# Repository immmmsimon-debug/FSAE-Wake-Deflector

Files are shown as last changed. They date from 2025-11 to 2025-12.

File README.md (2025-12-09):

# FSAE-Wake-Deflector
* The goal of this project is to design an aerodynamic wake deflector to manage the turbulent flow (“dirty air”) generated by the front tires of an FSAE car. This flow interferes with the undertray and side channel, reducing downforce and stability. The deflector aims to shield the side channel inlet from tire wake and to generate vortices that enhance undertray performance during both straight-line and cornering conditions.

## Fundamentals: 
- Open-wheel cars, including Formula SAE designs, suffer from highly turbulent flow around the front tires. As the tire rotates, the airflow separates along its shoulders, forming strong lateral vortices and a low-energy wake behind it. This unsteady, chaotic region—often called “dirty air”—contains low total pressure and high turbulence intensity.
When this wake interacts with the undertray or side channel inlet, it reduces the available clean flow that generates ground-effect downforce. In simple terms, the wake pollutes the undertray’s airflow, decreasing suction and stability.
### Flow Shielding and Redirection
- One approach to mitigating this is flow shielding, where an aerodynamic surface (such as a deflector wall) blocks or redirects the tire wake. However, this solution has limitations. A solid wall creates a stagnation zone on its upstream side and often leads to flow separation downstream, introducing drag and further turbulence.
Therefore, the better approach is flow redirection rather than pure blocking. By shaping the deflector with curvature or an airfoil profile, the air can be guided smoothly around the wake region, preserving flow energy and directing cleaner, higher-momentum air toward the undertray inlet.
### Vortex Generation and Control
- A more advanced strategy—used extensively in Formula 1—is vortex generation. Controlled vortices act like rotating tubes of high-energy air that can “seal” the underfloor, much like virtual skirts. The swirling motion of a vortex pulls faster air from above into the lower boundary layer, re-energizing it and delaying flow separation.
In the context of an FSAE car, the wake deflector can be designed with an airfoil-like geometry or sharp turning edge to induce a pressure difference between its suction and pressure sides. The rolling-up of flow at the deflector’s tip produces a coherent vortex that travels along the side channel, maintaining undertray suction.<br />
However, vortex behavior is highly sensitive to its environment. Its strength, trajectory, and longevity depend on:
  - Pressure gradient along its path.
  - Proximity to solid surfaces, which induce viscous shear.
  - Contamination by surrounding turbulence, such as tire wake.
### Viscous Dissipation and Vortex Decay
- Even if a strong vortex is generated at the inlet, it can decay rapidly due to viscous dissipation. This term describes how internal friction within the air (viscosity) converts the vortex’s organized rotational kinetic energy into heat and small-scale turbulence.
As the vortex interacts with the ground plane and side channel walls, shear layers form that gradually sap its energy. The higher the viscosity effects and turbulence intensity, the faster this decay occurs.
### Application to FSAE Scale
- At the FSAE scale, vortices are smaller and more sensitive to Reynolds number effects. This means they dissipate faster than in F1-scale aerodynamics, where higher speeds sustain coherent vortex structures. Therefore, achieving a long-lived vortex in FSAE requires careful balance: it must be strong enough to survive viscous losses, but not so aggressive that it causes flow separation or drag.
Reference: Willem Toet, “Motorsport Diffusers,” Racetech Magazine, 2017.
(https://www.racetechmag.com/2017/08/willem-toet-explains-motorsport-diffusers/)

### Constraint
  Because the deflector mounts around the A-arm and runs very close to the ground, the design uses a modular, multi-panel approach with localized doubler plates and through-bolt attachments to prevent fastener shear-out in the carbon-fiber honeycomb sandwich. Sacrificial UHMW skid strips and aramid-reinforced outer plies protect the laminate from abrasion and low-energy ground strikes; skids are bolted to backing plates so they are quickly replaceable. Fastener regions are either through-bolted to a backing plate or use bonded aluminum doublers with stainless steel threaded inserts to spread bearing loads and prevent core crush. All quick-release hardware is installed over doublers and captive nut plates to enable rapid service while preserving structural integrity. In order to test the mounting and the height of the deflector, we made flat plate deflector that is the same size as the curve ones, to see how much will scrap off and does the deflector survibe the impact.
<p align="center">
  
Screenshot 2025-12-08 at 12 50 07 AM

</p>

## CFD Images of Baseline Design

- The baseline configuration was analyzed using CFD, focusing on total pressure (CPt) distribution. Lower CPt regions correspond to higher-speed flow, or turbulance zone. The way that we can differenciate is by looking at the shape of the and the way it change, since a vortex would be circular and push air arround it in the dircection of its rotation while turbulance would seem chaotic and unpredictable. 
The results show a vortex forming near the deflector and propagating toward the side channel inlet. The high-speed circular region in the CPt plot confirms vortex formation. However, the vortex weakens and dissipates before reaching the end of the side channel, indicating a loss of potential downforce. <br />

https://github.com/user-attachments/assets/b7ffb7f3-22c6-420c-961b-e3214d9e8f9d

- In this video and  image we can see the vortex generated by the deflector and its position in relation to the side channel inlet by the looking at the CPt, see that there is a high air speed zone in a circular shape. As the vortex progress through the side channel we can see that it does not survibe at the lowest point of the side channel losing potential downforce being created, there are some assumption as to why this happend. 
     - The vortex core is too weak to survive the full channel length.
     - The channel geometry is too low, causing early vortex breakdown.
     - Insufficient clean flow enters the inlet, with some of the tire wake contaminating the vortex despite the deflector wall.
- In the baseline CFD, the observed weakening of the vortex near the outlet of the side channel can be explained by viscous dissipation combined with insufficient clean flow. The tire wake likely increases turbulence intensity at the inlet, causing the vortex core to diffuse and lose coherence before reaching the diffuser exit.
To counteract this, a stronger or more coherent vortex can be generated by:
Increasing the pressure differential across the deflector (via camber or higher angle of attack).
Providing clean, attached flow to the deflector leading edge.
Adjusting vortex placement so it travels through regions of favorable pressure gradient and minimal wall interference.

  <p align="center">
    Screenshot 2025-11-12 at 1 16 56 PM
    bottom

  </p>

- Due to the deadline that we have a limited resource the CFD is run in a 6 degree yaw enviroment with air speed of 15m/s. This was taken from the average yaw angle that we have experience during previous competition. 
 
## Iteration 6-17 Concepts
  Some way we can solve this by either creating a stronger vortex or to relocate the vortex. In order to create a strong vortex I utilze the pressure diffenrece create by a airfoil geometry. Furthermore due to the shape there is less likely a chance of flow seperation from the airfoil meaning that it will be able to operate at various yaw angle. However the vortex cannot be to large since the side channel nozzle  might cause the vortex to burst, and ruin air flow. 

## Iteration 6-17 Result
  The result where good however, due to the way that the airfoil is mounted I had to cut into the airfoil which result in flow seperation and unwanted turbulance air entering the side channel. Thus is would not be a good implementaiont, however this concept will still be keep in mind. 

** Due to the continous change to CFD settings more up to date runs are not comparable to run at the start. Due to the fact that we would need to cut the airfoil in order to mount it, we assume that it will cost flow seperation, thus did not re run the airfoil concept with more up to date settings. **

## Iteration 18 - 46

  Tyring to avoid the vertical airfoil, these iteration rely on a curve flat plate similar to that of old f1 barge board: simple, easy to mount. 
  <p align="center">
  Screenshot 2025-12-05 at 7 08 22 PM
  </p>

  The concept worked well and was able to generate a powerful vortex however, the vortex generated was dying due to the lack of clean air. This is cause by the agressive curve that these delflector have in order to generate a stronge vortex, but in that process the tire wake was able to get under the curve and into the side channel, thus straving the delfector vortex. 

## Iteration 47 - 80++ ( This concept is still being develop and optimize)

  Due to the fact that the flat plate worked really well, I used that concept as a foundation. In order to create a strong vortex without pulling in the wake of the tire, I need to have the deflector closer to the chassis in order to position the vortex further from the tire wake. However this leave the side channel inlet open that allow the wake to enter the side channel. Thus why not have 2 deflector, one deflector will on the outside(outboard), smaller and place close to the tire in order to stop the wake from getting into the side channel and the second one (inboard) will be place closer to the chassis due to the front wing main plain provding clean airflow. 
  Futhermore what we can do it to generate a vortex that will lift the dirty air away from the side channel foot plate, thus providing the side channel with clean air that will add more energy and create more downforce. 
  Due to the fact that this element is mounted in the suspension geometry, there are certain area where airflow will be bad, thus we should try to ignore the suspension by making it taller than the geometry. Now to make the upper vortex stronger we need a more agressive curve, however if we were to increase the curve lenght or angle the wheels will hit the deflector while turning, this the upper part is shifted toward the chassis even more. so that even though the top and bottom will end at the same place, the agressiveness of the curvature will be different. 
  However due to the fact that the upper vortex is generated so high above the side channel the desire effect would be less effective this we need something to drag down the vortex. Thus we can use a lift generating airfoil in order to create a downwash effect that will drag the vortex down with it. 

https://github.com/user-attachments/assets/98aec044-a053-49ec-971a-1726bc14465b

https://github.com/user-attachments/assets/e93339f5-973d-4e4d-87fe-c4102ed329bd

  As shown in the video, the outboard is controling the tire wake and preventing it from entering the side channel, not only that it is also creating a outwash that allow more clean air to enter the sidechannel later downstream. This allow the inboard to generate a powerful vortex that survive the entire side channel. Comparing to the baseline this set up was able to generate 40N+ in yaw and reduce the sensitivity from losing 11% of downforce from straight to a yaw angle of 6 to losing only 3%. 

  However there is a flaw to this design, due to the stronger upper vortex of the inboard it is actually pulling the tire wake and unwanted vortex from the front wing into the duct, which cause a decrease in mass flow to the radiator thus decreasing cooling. 

  With new iteration in development,
    I am planning to lower the heght of the inboard inorder to generate the vortex at a lower height, or turn the inboard into a flat plate in the x plane, however this would weaken the upper vortex. 
    - Criteria moving foward
      - Lower the upper vortex, or move it further away from the duct
      - Make it easier to manufracture
      - Make it easier to mount
        - Due to the curve geometry we cannot mount it the same way that we did last year, thus either the curvature need to change or a 3D adapter will need to be made, however this would also increase the weight of a already heavy aero package. Thus I have to look for a simplier design that still uphold the performance.

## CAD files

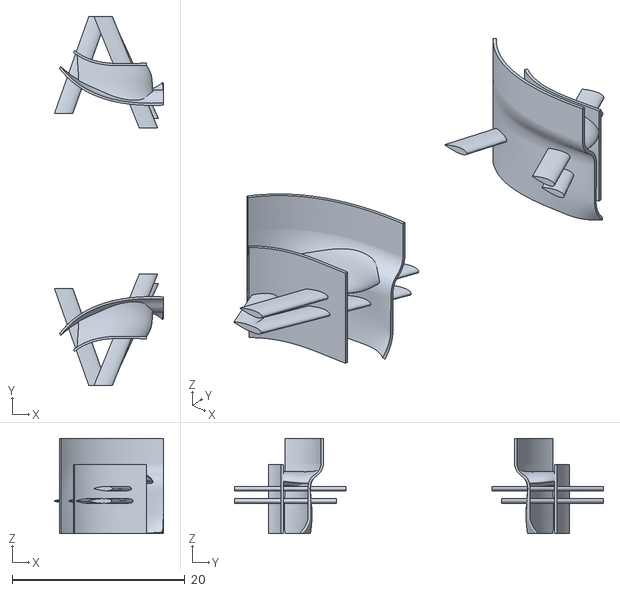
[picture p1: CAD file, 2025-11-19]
Deflector.052.stl
12.6 x 42.7 x 11.0

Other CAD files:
Deflector.048.prt
Deflector.051.prt

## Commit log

2025-11-06 Add files via upload
    This is iteration 48:
    - The vortex generator is moved closer to the chassis to create a stronger vortex that will survive the undertray under yaw condition.
    - Due to that, a second deflector is added so that the tire wake does not enter the undertray
    Problem:
    The primary deflector is now generating its own dirty air along with the stronger vortex, although performance has increased by 5%, more could be gained if the geometry can be modified to reduce the dirty air and strengthen the vortex.
    [Deflector.048.prt]
2025-11-13 Enhance README with detailed project insights
    Expanded project description to clarify the purpose and mechanics of the aerodynamic wake deflector. Added detailed sections on flow shielding, vortex generation, and CFD analysis results.
2025-12-08 Revise deflector design constraints for clarity and detail
    Refined the design constraints for the deflector, emphasizing a modular approach and detailing materials and assembly methods for durability and serviceability.
2025-12-08 Expand constraint section with deflector testing details
    Added a description of testing the deflector's mounting and height with a flat plate deflector.
